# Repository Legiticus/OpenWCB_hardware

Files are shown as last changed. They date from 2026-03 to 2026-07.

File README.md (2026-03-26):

# OpenWCB
Open WCB is an app controlled WebSocket powered device capable of controlling higher voltage motors than typical RC applications in
real time. It is primarily for developers, prototypes and RC enthusiasts who are looking for a easy solution to remotely control higher
voltage components in real time. This is accomplished by using an esp32 connected to multiple high voltage motor controllers while
broadcasting a local network that clients can join to connect with the board and control via a persistent WebSocket connection.

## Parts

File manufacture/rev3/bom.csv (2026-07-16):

Designator | Footprint | Quantity | Value | LCSC Part #
C1, C10, C13, C15, C16, C5 | 0805 | 6 | 100nF | C49678
C11, C12 | 0805 | 2 | 10µF | C83170
C14, C9 | CP_Radial_D10.0mm_P5.00mm | 2 | 1000µF | C233098
C2, C3, C7, C8 | 0805 | 4 | 220nF | C513710
C4, C6 | 0805 | 2 | 1nF | C51210
R1, R2 | 0805 | 2 | 15k | C17475
R10, R6 | 0805 | 2 | 1k | C17513
R11, R3, R7 | 0805 | 3 | 10k | C17414
R5, R9 | 0805 | 2 | 510 | C2907333
U2, U6 | TO127P1500X440-8N | 2 | IFX007T | C6968485
U4, U5 | Texas_HTSOP-8-1EP_3.9x4.9mm_P1.27mm_EP2.95x4.9mm_Mask2.4x3.1mm_ThermalVias | 2 | DRV8871DDA | C1556867

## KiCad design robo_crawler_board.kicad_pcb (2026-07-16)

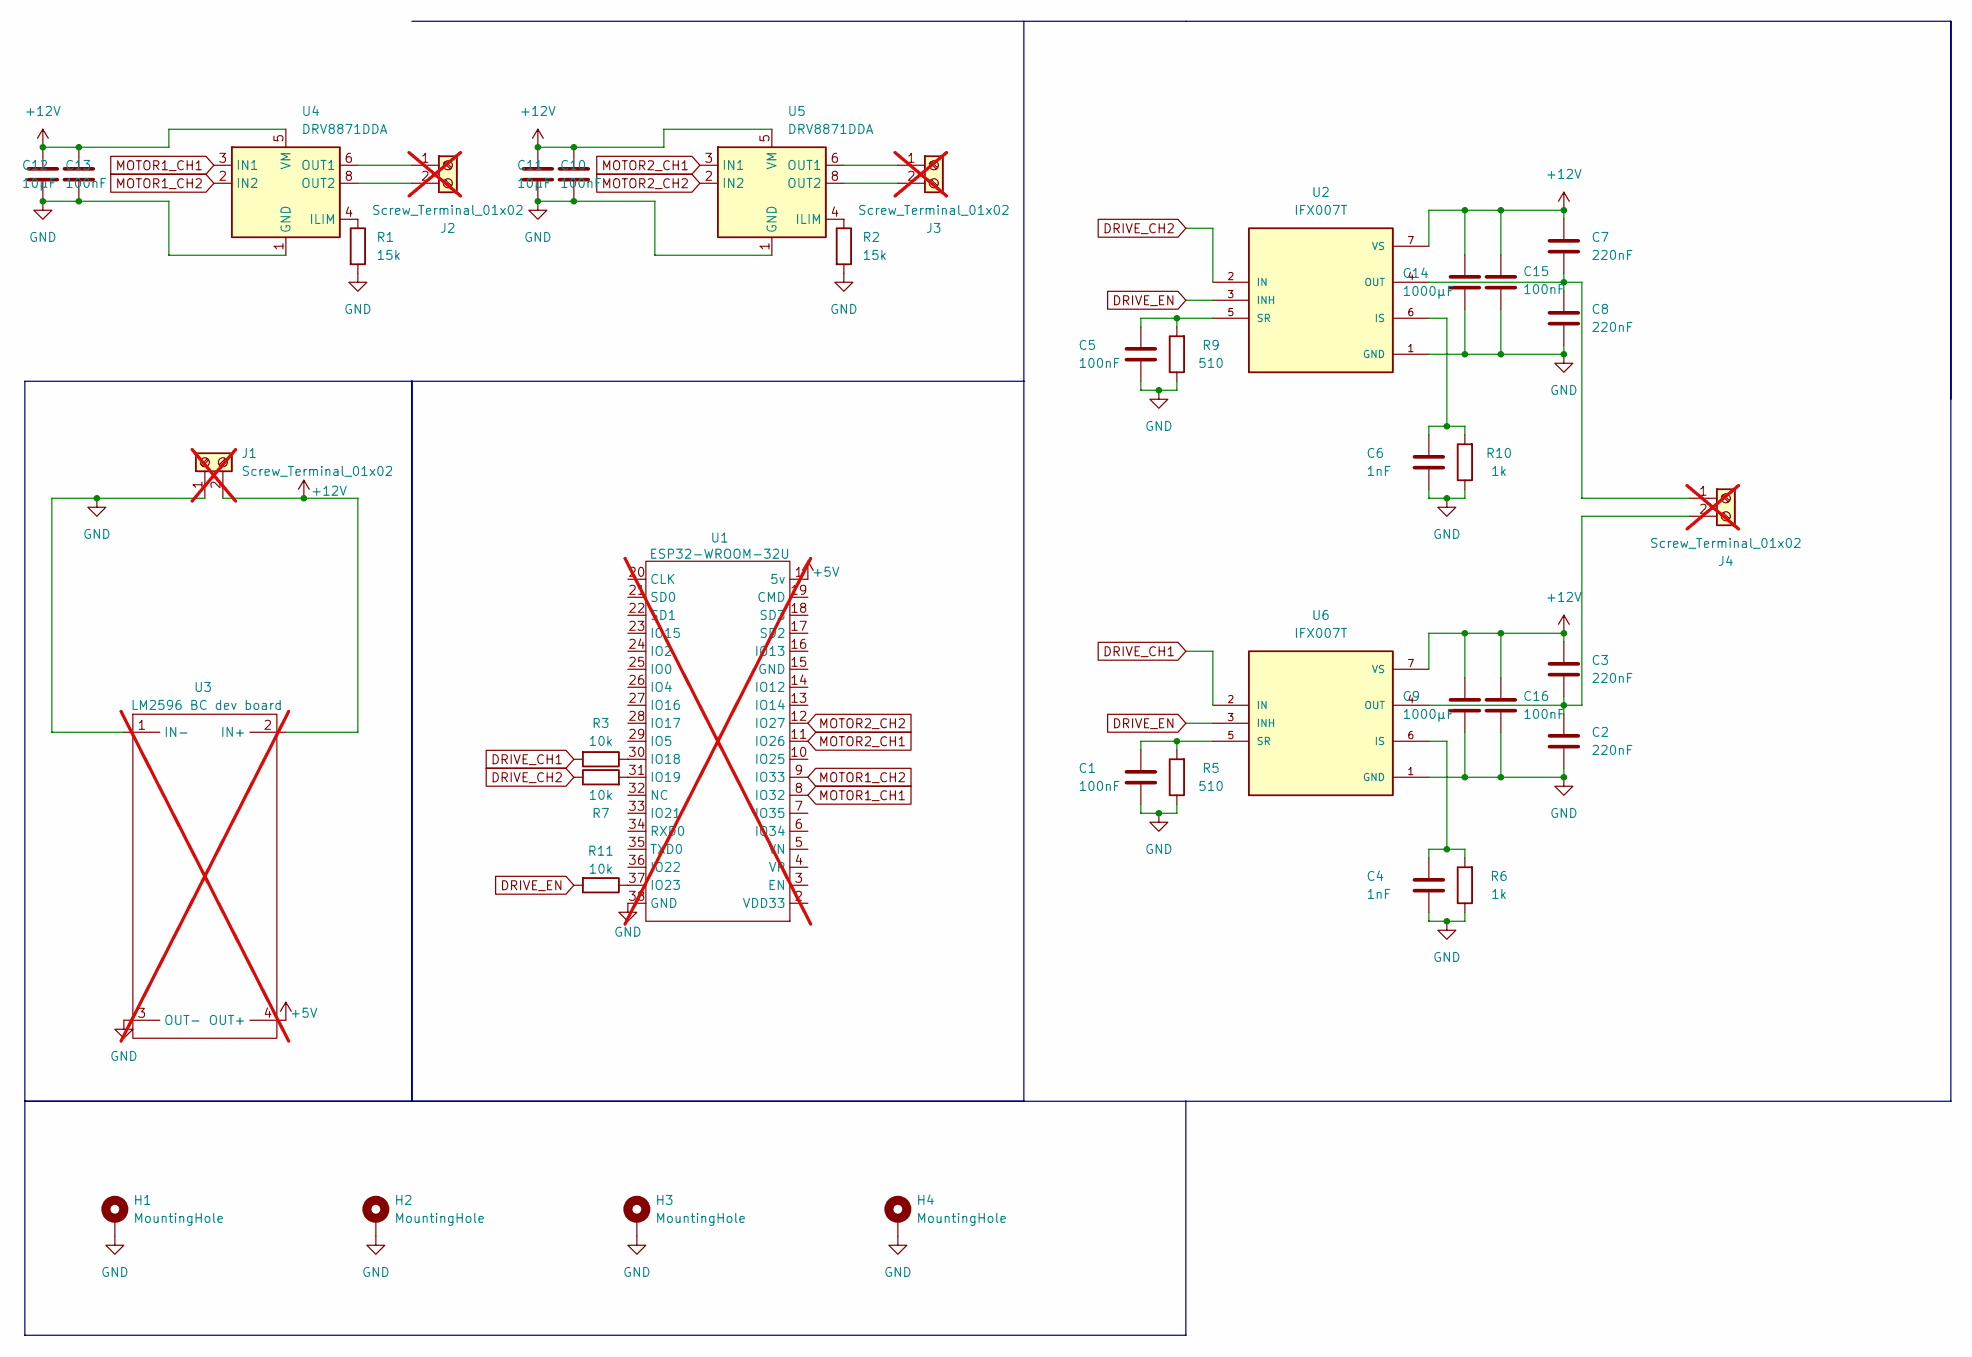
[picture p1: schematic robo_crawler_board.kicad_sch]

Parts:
C1, C5, C10, C13, C15, C16: 100nF; C_0805_2012Metric; LCSC Part Number C49678
C2, C3, C7, C8: 220nF; C_0805_2012Metric; LCSC Part Number C513710
C4, C6: 1nF; C_0805_2012Metric; LCSC Part Number C51210
C9, C14: 1000µF; CP_Radial_D10.0mm_P5.00mm; LCSC Part Number C233098
C11, C12: 10µF; C_0805_2012Metric; LCSC Part Number C83170
H1, H2, H3, H4: MountingHole; MountingHole_2.2mm_M2_Pad
J1, J2, J3, J4: Screw_Terminal_01x02; TerminalBlock_bornier-2_P5.08mm; not fitted
R1, R2: 15k; R_0805_2012Metric; LCSC Part Number C17475
R3, R7, R11: 10k; R_0805_2012Metric; LCSC Part Number C17414
R5, R9: 510; R_0805_2012Metric; LCSC Part Number C2907333
R6, R10: 1k; R_0805_2012Metric; LCSC Part Number C17513
U1: esp32-32u; Manufacturer Part ESP32-WROOM-32U; LCSC Part Name ESP32-WROOM-32U; not fitted
U2, U6: IFX007T; TO127P1500X440-8N; PARTREV 1.0; LCSC Part Number C6968485
U3: LM2596 DC-DC Buck Converter; not fitted
U4, U5: DRV8871DDA; Texas_HTSOP-8-1EP_3.9x4.9mm_P1.27mm_EP2.95x4.9mm_Mask2.4x3.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; LCSC Part Number C1556867

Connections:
+5V: U1.1 (5v), U3.4 (OUT+)
+12V: C3.1, C7.1, C9.1, C10.1, C11.1, C12.1, C13.1, C14.1, C15.1, C16.1, J1.2, U2.7 (VS), U3.2 (IN+), U4.5 (VM), U5.5 (VM), U6.7 (VS)
DRIVE_CH1: R3.2, U6.2 (IN)
DRIVE_CH2: R7.1, U2.2 (IN)
DRIVE_EN: R11.2, U2.3 (INH), U6.3 (INH)
GND: C1.2, C2.2, C4.2, C5.2, C6.2, C8.2, C9.2, C10.2, C11.2, C12.2, C13.2, C14.2, C15.2, C16.2, H1.1, H2.1, H3.1, H4.1, J1.1, R1.2, R2.2, R5.1, R6.1, R9.1, R10.1, U1.38 (GND), U2.1 (GND), U3.1 (IN-), U3.3 (OUT-), U4.1 (GND), U4.7 (GND), U4.9 (GND), U5.1 (GND), U5.7 (GND), U5.9 (GND), U6.1 (GND)
MOTOR1_CH1: U1.8 (IO32), U4.3 (IN1)
MOTOR1_CH2: U1.9 (IO33), U4.2 (IN2)
MOTOR2_CH1: U1.11 (IO26), U5.3 (IN1)
MOTOR2_CH2: U1.12 (IO27), U5.2 (IN2)
unnamed: J2.1, U4.6 (OUT1)
unnamed: J2.2, U4.8 (OUT2)
unnamed: J3.1, U5.6 (OUT1)
unnamed: J3.2, U5.8 (OUT2)
unnamed: C7.2, C8.1, J4.1, U2.4 (OUT), U2.8 (OUT)
unnamed: C2.1, C3.2, J4.2, U6.4 (OUT), U6.8 (OUT)
unnamed: R3.1, U1.30 (IO18)
unnamed: R7.2, U1.31 (IO19)
unnamed: R11.1, U1.37 (IO23)
unnamed: C6.1, R10.2, U2.6 (IS)
unnamed: C5.1, R9.2, U2.5 (SR)
unnamed: R1.1, U4.4 (ILIM)
unnamed: R2.1, U5.4 (ILIM)
unnamed: C4.1, R6.2, U6.6 (IS)
unnamed: C1.1, R5.2, U6.5 (SR)

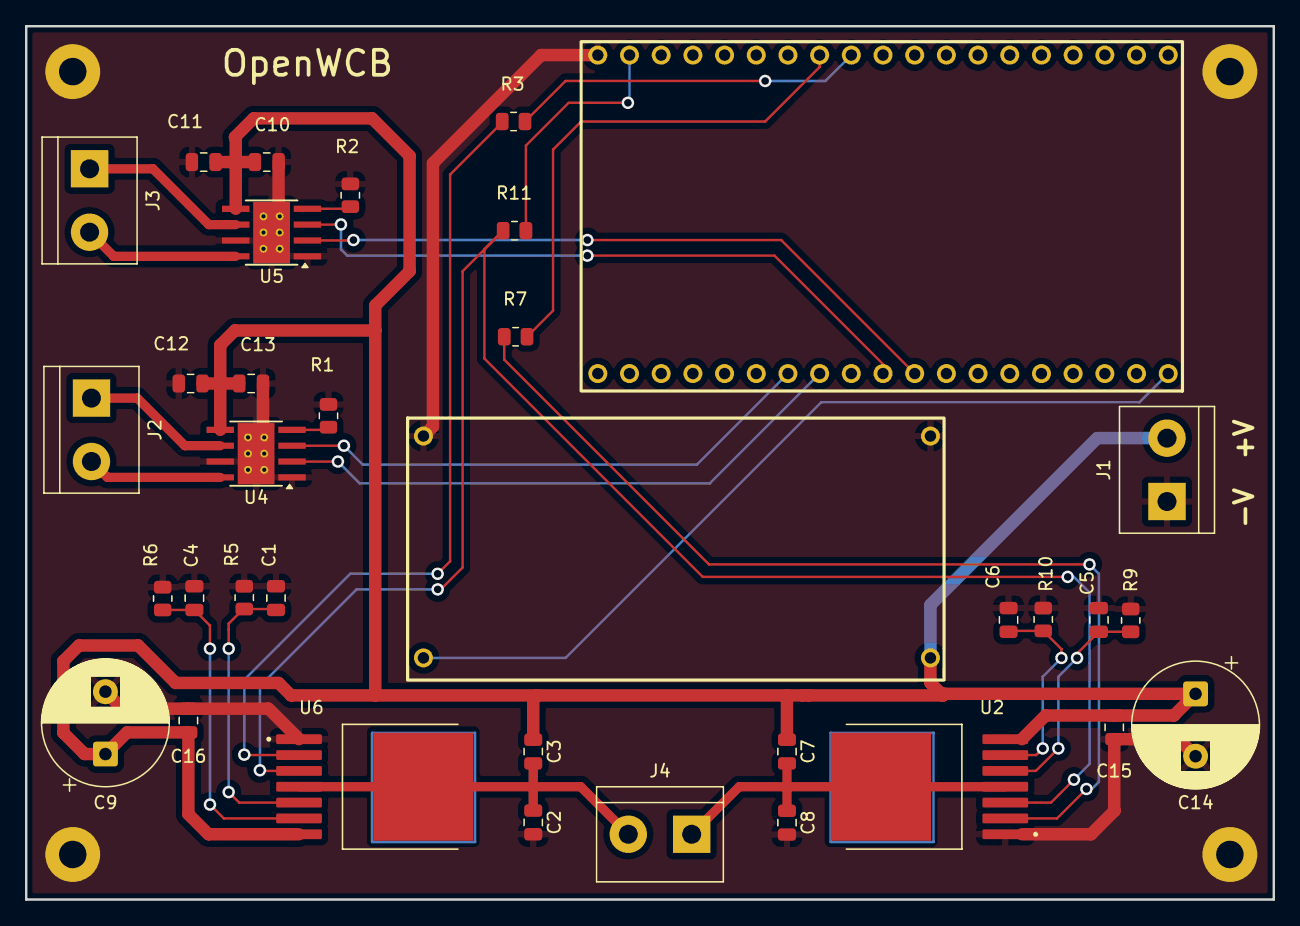
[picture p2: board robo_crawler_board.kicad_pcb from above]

Board: 2 copper layers, 100.0 x 70.0 mm, 39 parts (0 on the bottom side), 25 nets.

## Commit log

2026-02-23 adjusted for EPL manufacturing
    [robo_crawler_board.kicad_pcb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]
2026-03-26 cleaning repo
    [deadzone_v1.kicad_pcb, deadzone_v1.kicad_sch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]
2026-03-26 Reworking board design
    [robo_crawler_board.kicad_pcb, robo_crawler_board.kicad_sch]
2026-03-26 tentative rev2
    [robo_crawler_board.kicad_pcb, robo_crawler_board.kicad_sch]
2026-03-30 rev 2
    [robo_crawler_board.kicad_pcb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]
2026-05-18 removed unnessesary controllers and adjusted layout
    [robo_crawler_board.kicad_sch]
2026-05-18 saving progress
    [robo_crawler_board.kicad_pcb, robo_crawler_board.kicad_sch]
2026-07-16 rev3 pcb done except ground planes
    [robo_crawler_board.kicad_pcb, robo_crawler_board.kicad_sch]
2026-07-16 added ground planes, drc errors need to be fixed
    [robo_crawler_board.kicad_pcb]
2026-07-16 resolved drc errors
    [robo_crawler_board.kicad_pcb]
2026-07-16 production rev3
    [bom.csv, designators.csv, positions.csv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]
